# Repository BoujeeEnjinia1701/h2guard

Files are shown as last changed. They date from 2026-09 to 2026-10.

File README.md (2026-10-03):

# H2Guard

     

**Area:** Hydrogen · **TRL:** 3 of 9 (proof of concept on paper) · **Value-engineering target:** USD 265 (estimated cost USD 411) · **Difficulty:** 3 of 5

A hydrogen leak detector and ventilation interlock for small labs, workshops and electrolyzer rooms: it senses hydrogen near the ceiling, runs a fan and cuts the supply when readings rise.

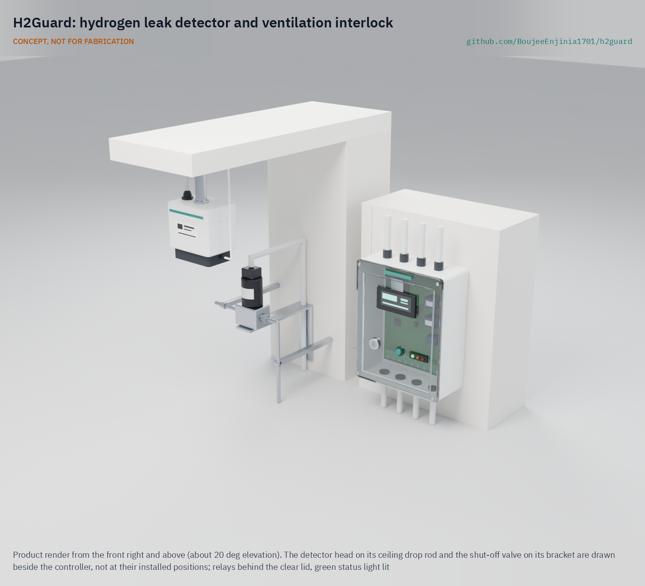
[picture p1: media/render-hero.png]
H2Guard: hydrogen leak detector and ventilation interlock, product render


[Exploded render](media/render-exploded.png) · [Detail render](media/render-detail.png) · [Interactive 3D model](media/viewer.html) · [Concept blueprint (PDF)](media/concept-blueprint.pdf) · [General arrangement HGD-DWG-001 (PDF)](cad/drawings/HGD-DWG-001.pdf) · [Sizing calculations](docs/04-calcs/01-sizing.md) · [Prototype build plan](docs/05-build-plan.md) · [Design decisions register](docs/06-design-decisions.md) · [Review note](docs/REVIEW.md)

## Concept rationale

Detection, ventilation and automatic shutoff form the basic safety chain for any room where hydrogen is used, and each link has to work when the others fail. H2Guard puts that chain in one small kit: a ceiling detector head with a catalytic sensor for the trip and a metal oxide sensor for early warning, a continuously running exhaust fan, and a normally closed valve that holds the supply open only while the controller, the sensors and the fan are all healthy. A hardware comparator can close the valve without the firmware, so a software bug cannot keep gas flowing.

It is open and garage-buildable because the people now starting to use hydrogen, teachers, technicians and small startups, need to see how a safety system decides, not just trust a sealed box. Every set point and failure response is written down, the self-built parts run on 24 V DC from a certified supply, and the parts are off the shelf. It is a teaching and research prototype, not a certified gas detection system, and the documents say where it falls short of one.

## Burning platform

Hydrogen is moving into classrooms, startups and small labs faster than safe practice is reaching them. Installed water electrolysis capacity reached about 2 GW in 2024, with more than 1 GW added in the first seven months of 2025 ([IEA, Global Hydrogen Review 2025](https://www.iea.org/reports/global-hydrogen-review-2025/executive-summary)). The gas is flammable in air from about 4 % to 74 % by volume, ignites with about 0.02 mJ, and collects under ceilings in poorly ventilated rooms ([US DOE](https://www1.eere.energy.gov/hydrogenandfuelcells/pdfs/h2_safety_fsheet.pdf)).

Small-scale accidents show the cost of missing safeguards. In 2016 a hydrogen and oxygen mixture exploded in a University of Hawaii lab, costing a researcher an arm; the state safety regulator cited the university for 15 violations with $115,500 in fines ([C&EN, 2016](https://cen.acs.org/articles/94/web/2016/09/University-Hawaii-fined-115500-lab.html)), later settled at nine violations and $69,300 ([Honolulu Star-Advertiser, 2016](https://www.staradvertiser.com/2016/10/07/breaking-news/state-agrees-to-reduced-violations-fines-in-uh-lab-explosion/)). In 2019 a hydrogen tank used by a fuel cell company at a technopark in Gangneung, South Korea, exploded, killing two people and injuring six ([Korea Herald](https://www.koreaherald.com/article/2006624)). An analysis of the European HIAD 2.0 incident database found organizational factors in about half of the relevant events ([Wen et al., 2022](https://www.sciencedirect.com/science/article/pii/S0360319922012976)), which is the case for safeguards that act automatically.

## Where it could be used

### By industry

| Industry | Use |
| --- | --- |
| Education | Protection and teaching aid for school and university hydrogen demonstrations, including the lab's H2Bench |
| Hydrogen and fuel cell startups | Interim protection for a small test room before a certified system is installed |
| Analytical laboratories | Room-level leak detection near hydrogen generators used as gas chromatography carrier gas |
| Materials handling and backup power | Monitoring battery charging rooms, where US rules require ventilation for gases from charging batteries ([OSHA 1910.178(g)(2)](https://www.osha.gov/laws-regs/regulations/standardnumber/1910/1910.178)), and small fuel cell backup rooms |
| Vocational training | Hands-on teaching of set points, interlocks and bump testing for hydrogen technicians |
| Makerspaces | A clear rule set and hardware for members experimenting with electrolysis |

### By country or region

| Country or region | Why it matters there |
| --- | --- |
| United States | After the 2016 University of Hawaii lab explosion, the state safety regulator cited the university for 15 violations with $115,500 in fines ([C&EN, 2016](https://cen.acs.org/articles/94/web/2016/09/University-Hawaii-fined-115500-lab.html)), settled later that year at nine violations and $69,300 ([Honolulu Star-Advertiser, 2016](https://www.staradvertiser.com/2016/10/07/breaking-news/state-agrees-to-reduced-violations-fines-in-uh-lab-explosion/)) |
| South Korea | A hydrogen tank explosion at a Gangneung technopark in 2019 killed two visitors from venture businesses and research groups ([Korea Herald](https://www.koreaherald.com/article/2006624)) |
| European Union | The EU hydrogen strategy aims for at least 40 GW of renewable hydrogen electrolyzers by 2030 ([European Commission, COM(2020) 301](https://eur-lex.europa.eu/legal-content/EN/TXT/?uri=CELEX:52020DC0301)), which needs many trained technicians |
| China | Holds 65 % of the world's installed and committed electrolyzer capacity ([IEA](https://www.iea.org/reports/global-hydrogen-review-2025/executive-summary)), with a large and growing training need |
| India | The National Green Hydrogen Mission targets at least 5 Mt per year of green hydrogen by 2030 and includes a skills program ([PIB, 2023](https://www.pib.gov.in/PressReleasePage.aspx?PRID=1888547)); colleges and startups need low-cost lab safety |
| Namibia | The government runs a national green hydrogen program ([Namibia Green Hydrogen Programme](https://gh2namibia.com/)); the vice-chancellor of the Namibia University of Science and Technology has warned of a talent gap of up to 130,000 workers by 2040 ([The Namibian, 2025](https://www.namibian.com.na/namibia-risks-130-000-worker-shortage-in-green-hydrogen-sector/)), and the university's IGNITE GH2 project is retraining 685 unemployed graduates and 40 instructors ([NUST, 2026](https://www.nust.na/igniting-namibias-green-hydrogen-dream-science-building-national-tvet-workforce-green-hydrogen)) |

## What sparked the idea

The idea traces back to the New London School explosion in Texas on March 18, 1937. Gas from a faulty connection on a cheap residue gas line collected unnoticed in a nearly closed space beneath the school and exploded, killing about 298 students and teachers; the most important result was a state law requiring a distinctive malodorant in commercial and industrial gas so that people could smell a leak ([Texas State Historical Association, Handbook of Texas](https://www.tshaonline.org/handbook/entries/new-london-school-explosion)). That fix does not carry over to hydrogen. It is colorless and odorless, and there are no known odorants light enough to travel with it, so by the time an odorant could be smelled the gas may already be above its flammability limit ([OSHA](https://www.osha.gov/green-jobs/hydrogen/fire-explosion)). A room that uses hydrogen therefore needs what the nose cannot give it: an electronic detector at the ceiling, where the gas collects, tied to ventilation and a valve that shuts the supply without waiting for a person to notice. H2Guard is that chain, sized for the classrooms and small labs now taking up hydrogen.

## Problem

Small hydrogen setups in schools and startups often have no gas detection or interlock because commercial systems are priced for industrial plants.

Full problem statement: [docs/01-problem.md](docs/01-problem.md)

## Concept

A detector head at the ceiling above the hydrogen source measures 0 to 100 % of the lower flammability limit (LFL). A wall controller keeps an exhaust fan running and holds a normally closed valve on the supply open. At 10 % LFL it warns and boosts the fan; at 25 % LFL it closes the valve, sounds the alarm and latches until a key reset. Power loss, sensor faults, a stopped fan, lost airflow (a pressure switch on the fan inlet) or a crashed controller also close the valve, and a hardware comparator trip works without the firmware. The TRL 3 calculations give 35.7 s from a 5 L/min leak to the valve closing (with an assumed 30 s sensor response), and about 5 % LFL in the 30 m3 reference room with the fan running. They also show that the design leak trips the system at once only if the detector head is on the plume axis above the leak. Two rules accepted by Amish cover the rest: a warning held for 5 min also closes the valve (about 5.6 min for the design leak off the axis), and the head hangs from the ceiling on a short drop rod directly above the likely leak point.

Full design precis: [docs/02-concept.md](docs/02-concept.md) · Requirements: [docs/03-requirements.md](docs/03-requirements.md) · Calculations: [docs/04-calcs/01-sizing.md](docs/04-calcs/01-sizing.md) · Decisions: [DDR-001](docs/decisions/0001-trl2-review-decisions.md), [DDR-002](docs/decisions/0002-recommendations-accepted.md), [DDR-003](docs/decisions/0003-design-for-construction.md), [register](docs/06-design-decisions.md)

## Key components

- Detector head on a ceiling drop rod, with a catalytic hydrogen sensor (0 to 100 % LFL) and a metal oxide early-warning sensor, behind thin sintered flame arrestors, with a drip skirt that doubles as a bump test cup
- Controller in a clear-lid box with an independent hardware trip (latched comparator and series relay), display, key-switch reset, event log, a dry-contact output for the host bench and a bump test gas port
- Certified 24 V DC power supply
- 150 mm mixed-flow exhaust fan at high level, running continuously, with a differential pressure switch that proves airflow, and a low-level make-up air grille
- Normally closed 24 V DC solenoid valve rated for hydrogen on the supply
- Oxygen sensor option where inert gas cylinders share the room
- Sounder and beacon

The priced bill of materials is in [bom/bom.csv](bom/bom.csv). Value-engineering target: USD 265. Estimated cost of the constructable design: USD 411 (USD 146 over the target), at indicative prices; the [design decisions register](docs/06-design-decisions.md) lists the main cost drivers and savings worth trying. The parametric model is `cad/src/model.py`, with STEP and STL exports in `cad/step/` and `cad/stl/`.

## Building the prototype

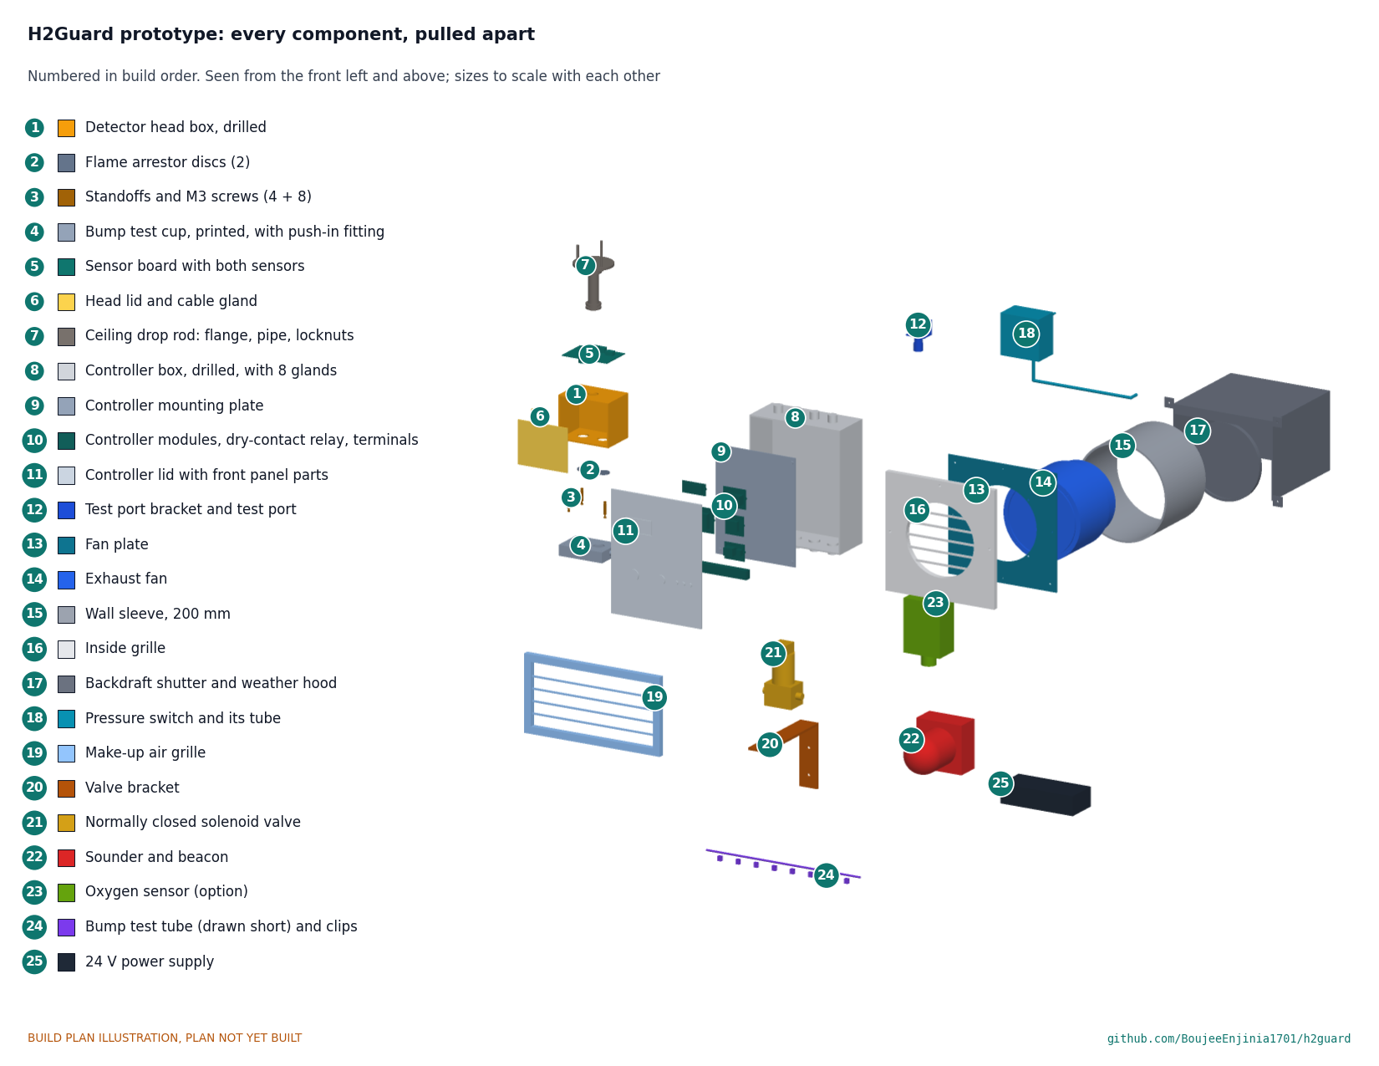
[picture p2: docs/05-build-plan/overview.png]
Every H2Guard component, pulled apart and numbered in build order


The [prototype build plan](docs/05-build-plan.md) (HGD-BLD-001) shows how to make and fit every component, with a making sketch for each made part, close-ups of the joints and a picture for each of the 15 assembly steps. Nine parts are made or drilled in a small workshop (the two boxes and the controller lid, the printed bump test cup, the sensor board and four aluminium brackets and plates); the rest are bought. Making the design buildable added standoffs, a mounting plate, a fan plate with a 200 mm wall sleeve and brackets for the test port and valve ([HGD-DDR-003](docs/decisions/0003-design-for-construction.md)). It is a plan: nothing has been built or tested.

## Safety

> Hydrogen is flammable in air from about 4 % to 74 % by volume. This is a research and teaching prototype and not a certified gas detection system; use certified equipment for any real installation. Its parts are not rated for hazardous areas. It protects only against small, flow-limited leaks, and only with its head hung directly over the leak point; keep hydrogen inventories small, and have gas fittings made and leak-tested by a competent person. Mains power enters only through a certified supply.

## Repository layout

| Folder | Contents |
| --- | --- |
| `docs/` | Problem, concept, requirements, calculations and design decisions |
| `cad/src/` | build123d Python source, the source of truth for all geometry |
| `cad/step/`, `cad/stl/` | Exported models for FreeCAD, other CAD tools and printing |
| `cad/drawings/` | 2D sketches and dimensioned drawings |
| `bom/` | Bill of materials |
| `electronics/` | KiCad schematics and PCB layouts |
| `firmware/` | Microcontroller code |
| `media/` | Renders, perspectives and photos |
| `build-log/` | Dated prototyping notes |

## Documentation

Controlled documents follow the portfolio [documentation standard](.kit/STANDARDS.md). Each carries a document ID (HGD-PRC-001 for the precis), a version and a revision history. Branded PDFs are built with `python .kit/render.py` and attached to GitHub Releases when a document is tagged, for example `HGD-PRC-001/v1.0`.

## Credits

Designed by Amish Chadha. See [CONTRIBUTORS.md](CONTRIBUTORS.md) for roles. To cite this design, use [CITATION.cff](CITATION.cff) (GitHub shows it as "Cite this repository").

AI assistance (Claude) was used to accelerate concept renders, prototype documentation and first-pass sizing calculations. Design direction and all decisions are Amish Chadha's, recorded in this repository's decision records (`docs/decisions/`).

## Licenses

- **Hardware** (CAD, drawings, BOM, electronics): [CERN-OHL-S v2](LICENSE)
- **Software** (firmware, scripts, notebooks): [MIT](LICENSE-SOFTWARE)

A project of the [Design Molecule](https://designmolecule.com) lab.

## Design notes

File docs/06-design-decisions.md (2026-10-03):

---
doc_id: HGD-DEC-001
title: H2Guard design decisions register
project: H2Guard
doc_type: Design decisions register
version: "0.4"
status: Draft
date: '2026-10-03'
author: Amish Chadha
license: CERN-OHL-S-2.0
revisions:
- version: "0.1"
  date: '2026-10-01'
  author: Amish Chadha
  change: Register opened with the build plan; open decisions gathered from the review note and the decision records; budget treated as a value-engineering target
- version: "0.2"
  date: '2026-10-02'
  author: Amish Chadha
  change: Amish approved the recommendations for open decisions 1 to 12 (HGD-DDR-003 accepted; head on a ceiling drop rod); moved to decisions made
- version: "0.3"
  date: '2026-10-02'
  author: Amish Chadha
  change: Decisions carried into the model, BOM and calculations; value engineering re-priced (USD 411); items to confirm for the drop rod, pressure switch and dry-contact relay
- version: "0.4"
  date: '2026-10-03'
  author: Amish Chadha
  change: "Amish accepted the cost overrun against the value-engineering target on 2026-10-03; row added to decisions made; value engineering section updated"
---

# H2Guard design decisions register

Every design decision still to be made, and every decision made, in one place. Each decision is argued in full in its decision record under `docs/decisions/` or in the review note; this register is the index Amish works from. The build plan (`docs/05-build-plan.md`) describes the design as it stands and does not list open decisions.

## Open decisions

None. All open decisions were decided on 2026-10-02.

## To confirm when parts are bought

| # | What to confirm | Why it matters | Source |
| --- | --- | --- | --- |
| 1 | The catalytic sensor's response time (t90), power and hydrogen output, from its datasheet | R4 assumes a t90 of 30 s; R1's 1 % LFL resolution needs the output | HGD-CAL-001, F3 |
| 2 | The sensor can is about 20 mm across and 17 mm tall | The standoff length sets its 2.2 mm gap above the disc | HGD-DDR-003, P4 |
| 3 | The head box has its lid on a 110 x 90 face | The ports, gland and drop rod hole assume it | HGD-DDR-003, P3 |
| 4 | The controller box's boss spacing and corner fixing holes | They set the mounting plate holes and the wall screws | HGD-DDR-003, P6, P8 |
| 5 | The fan's body fits a 200 mm sleeve (about 180 mm across or less) and has fixing holes in its inlet face | The fan plate holds it by those holes | HGD-DDR-003, P10 |
| 6 | The fan's curve gives at least 300 m³/h against about 60 Pa | R7 rests on an assumed curve | HGD-CAL-001, G3 |
| 7 | The valve has two tapped holes underneath, 36 mm apart, and is rated for hydrogen with a stated seat leak rate | The bracket holes; the leaking-seat fault in Table 4 of HGD-CAL-001 | HGD-DDR-003, P11; HGD-DDR-001, O5 |
| 8 | The pressure switch can be set to about 3 Pa (a low-range air switch) | The fan inlet tap gives only 5.7 Pa at the continuous flow; a common 20 Pa minimum switch would prove flow only on boost | HGD-CAL-001, G6; decision 6 |
| 9 | The floor flange, pipe nipple and conduit locknuts share one 1/2 in thread, and the ceiling takes the flange screws | The drop rod holds the head over the apparatus | HGD-CAL-001, E7; decision 2 |
| 10 | The dry-contact relay's contact rating suits H2Bench's supply cut-off circuit | H2Bench switches its own supply through it | Decision 9 |

## Value engineering

Value-engineering target: USD 265. Estimated cost of the constructable design: USD 411 (USD 146 over the target). The estimate comes from the 21-line bill of materials at indicative prices; the target is `budget_usd`, a hypothetical control target, not a limit. Two options are priced with quantity 0 and are not in the total: the oxygen sensor (USD 110) and the fan with its motor outside the air stream (USD 450, in place of the USD 55 fan). Main cost drivers and savings worth trying:

Amish accepted this overrun on 2026-10-03: the estimated cost of USD 411 against the USD 265 target (USD 146 over). Amish: "Cost over target - i accept all the cost variations and overruns". It stays reported against the target as an accepted overrun, and the savings below remain worth trying.

- The largest lines are the hydrogen-rated valve (USD 95), the exhaust fan with its grille, sleeve, shutter and hood (USD 55), the catalytic sensor (USD 35), the pressure switch and tubing (USD 30) and the controller modules (USD 25). Together they are about 60 % of the cost.
- Making the design constructable added USD 25: the made brackets and plates (USD 14), the 200 mm wall sleeve (USD 5), standoffs, screws and epoxy (USD 4) and the cup's push-in fitting and tube clips (USD 2).
- The decisions of 2026-10-02 added USD 122: the hydrogen-rated valve (USD 65 more than the brass valve), the pressure switch and tubing (USD 30), the ceiling drop rod (USD 11), the dry-contact relay and terminal (USD 6), the clear-lid controller box (USD 5) and more cable (USD 5).
- Savings worth trying: a printed controller mounting plate in place of aluminium sheet (about USD 3); buying the fan as a kit with its own shutter and hood; one combined controller board at TRL 4 in place of separate bought modules; and, where the room already has mechanical extract at high level, using it in place of the kit fan and grille (USD 63), which would bring the kit to about USD 348; and the brass valve at USD 30, if its maker states hydrogen compatibility and a seat leak rating and it passes the seat leak proof test (USD 65 less).

## Decisions made

| Date | Decision | Decided by | Record |
| --- | --- | --- | --- |
| 2026-09-25 | D1 to D9: catalytic plus metal oxide sensors (certified sensor as the upgrade); set points 10 % and 25 % LFL; normally closed valve; continuous ventilation with boost; inventory rule (R9); key-switch reset and one head per room; a university teaching lab first; independent hardware trip; 24 V DC with a certified supply | Amish: "i accept all your recommendations, go with them across all repos." | HGD-DDR-001, HGD-DDR-002 |
| 2026-09-25 | Budget figure USD 265, now treated as the value-engineering target | Amish, same instruction; on 2026-10-01: "the budgets are a hypothethical control target to ensure we are thinking along a value engineering lens" | HGD-DDR-002 |
| 2026-09-25 | Timed escalation: a warning held 5 min closes the valve and latches | Amish, same instruction | HGD-DDR-002 |
| 2026-09-25 | Head placement rule: a head directly above each likely leak point; offset limit set by test at TRL 4 | Amish, same instruction | HGD-DDR-002 |
| 2026-09-25 | R13 scope: the fan and grille wall openings are builder's work | Amish, same instruction | HGD-DDR-002 |
| 2026-09-25 | H2Bench to reflect the inventory rule | Amish, same instruction | HGD-DDR-002 |
| 2026-09-30 | Make the design physically buildable while drawing the build plan; keep open decisions out of the build plan | Amish: "If you are realising that the design cannot be built as per concept - fix the design assumptions to match and be physically feasible as you draw the illustrations." | HGD-DDR-003 (changes accepted on 2026-10-02, below) |
| 2026-10-02 | Design for construction accepted: the changes P1 to P11, as made; the head position is settled separately (decision 2) | Amish: "i approve your recommendations for all 555 open decisions." | HGD-DDR-003, Table 1 |
| 2026-10-02 | The head hangs from the ceiling on a drop rod directly over the apparatus; wall mounting is allowed only if the TRL 4 plume test shows a trip at the wall position (the wall position puts the ports 260 mm from the apparatus centre against a plume radius of about 141 mm) | Amish: "i approve your recommendations for all 555 open decisions." | HGD-DDR-003, A1 |
| 2026-10-02 | Fan motor in the sleeve accepted for the supervised teaching prototype; any room used without close supervision gets a fan with its motor outside the air stream | Amish: "i approve your recommendations for all 555 open decisions." | HGD-DDR-003, A2 |
| 2026-10-02 | An oxygen sensor is added, as a standard kit option, whenever inert gas cylinders share the room | Amish: "i approve your recommendations for all 555 open decisions." | HGD-DDR-001, O2 |
| 2026-10-02 | Set points and the inventory rule come from the stricter of the national code and ISO 26142, and from the host institution's safety office where its rules are stricter; 10 % and 25 % LFL stay the defaults | Amish: "i approve your recommendations for all 555 open decisions." | HGD-DDR-001, O3 |
| 2026-10-02 | A differential pressure switch at the fan proves airflow | Amish: "i approve your recommendations for all 555 open decisions." | HGD-DDR-001, O4 |
| 2026-10-02 | The valve is rated for hydrogen with a stated seat leak rate; the low-cost brass valve is accepted only if its maker states hydrogen compatibility and a seat leak rating and it passes a seat leak proof test at TRL 4 | Amish: "i approve your recommendations for all 555 open decisions." | HGD-DDR-001, O5 |
| 2026-10-02 | The 1 % full-span bump test trips the system, as planned; the pass level is set once the cup delivery factor is measured | Amish: "i approve your recommendations for all 555 open decisions." | Review note, 2026-09-25 |
| 2026-10-02 | A dry-contact relay output that opens on a trip or loss of power is added, for H2Bench to cut its own supply | Amish: "i approve your recommendations for all 555 open decisions." | Review note, 2026-09-25 |
| 2026-10-02 | The render layout is kept, with a caption saying the head and valve are drawn beside the controller | Amish: "i approve your recommendations for all 555 open decisions." | Review note, 2026-09-26, item 1 |
| 2026-10-02 | A clear-lid IP65 controller box, added to the BOM at its next revision | Amish: "i approve your recommendations for all 555 open decisions." | Review note, 2026-09-26, item 2 |
| 2026-10-02 | Leaving the fan, grille, sounder, beacon and supply out of the product renders accepted | Amish: "i approve your recommendations for all 555 open decisions." | Review note, 2026-09-26, item 3 |
| 2026-10-03 | Cost overrun accepted: the estimated cost of USD 411 against the USD 265 target (USD 146 over) | Amish: "Cost over target - i accept all the cost variations and overruns" | [REVIEW.md](REVIEW.md), session 2026-10-03 |

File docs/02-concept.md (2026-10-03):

---
doc_id: HGD-PRC-001
title: H2Guard design precis
project: H2Guard
doc_type: Design precis
version: "0.7"
status: Draft
date: '2026-10-02'
author: Amish Chadha
license: CERN-OHL-S-2.0
revisions:
- version: "0.1"
  date: '2026-09-25'
  author: Amish Chadha
  change: Initial scaffold
- version: "0.2"
  date: '2026-09-25'
  author: Amish Chadha
  change: Populate to TRL 2 (architecture, components, first-order numbers, design choices, safety, media)
- version: "0.3"
  date: '2026-09-25'
  author: Amish Chadha
  change: TRL 3 update; design choices adopted for TRL 3 per HGD-DDR-001 (pending Amish's review); numbers from HGD-CAL-001; fan re-specified, thinner arrestors, bump test cup and port added; series trip relay; parametric model and drawing HGD-DWG-001
- version: "0.4"
  date: '2026-09-25'
  author: Amish Chadha
  change: Recommendations accepted by Amish (DDR-002); timed escalation firmware rule, head placement rule, budget $265, R13 scope; drawing HGD-DWG-001 to Rev P2
- version: "0.5"
  date: '2026-10-01'
  author: Amish Chadha
  change: Design made constructable (HGD-DDR-003) with a build plan (HGD-BLD-001); cost against the value-engineering target; drawing HGD-DWG-001 to Rev P4
- version: "0.6"
  date: '2026-10-02'
  author: Amish Chadha
  change: "Decisions of 2026-10-02 carried in: ceiling drop rod, pressure switch, hydrogen-rated valve, oxygen sensor option, set point sources, bump test, relay output, clear lid, fan motor rule"
- version: "0.7"
  date: '2026-10-02'
  author: Amish Chadha
  change: Model, BOM and calculations updated to the decisions of 2026-10-02 (HGD-CAL-001 v0.4); components table, key numbers and safety notes brought into line; drawing HGD-DWG-001 to Rev P5
---

# H2Guard design precis

H2Guard protects one small room where hydrogen is used. A detector head at the ceiling carries a catalytic sensor that reads 0 to 100 % of the lower flammability limit (LFL) and a metal oxide sensor for early warning. A wall controller at chest height keeps a 150 mm exhaust fan running at high level, holds a normally closed solenoid valve on the hydrogen supply open only while all is well, and drives a sounder and beacon. At 10 % LFL it warns and boosts the fan; at 25 % LFL it closes the valve and latches the alarm. Loss of power, a sensor fault, a stopped fan, lost airflow or a crashed controller all close the valve, and a hardware comparator opens a relay in series with the valve without the firmware. The TRL 3 calculations (HGD-CAL-001) give 35.7 s from a leak to the valve closing with an assumed 30 s sensor t90, about 5 % LFL in the 30 m3 room for the 5 L/min design leak with the fan running, and an estimated cost of USD 411 for the constructable design against a USD 265 value-engineering target (USD 146 over). A warning held for 5 min also closes the supply, so a leak that the head sees off the plume axis is stopped within about 6 min. H2Guard is a research and teaching prototype, not a certified gas detection system.

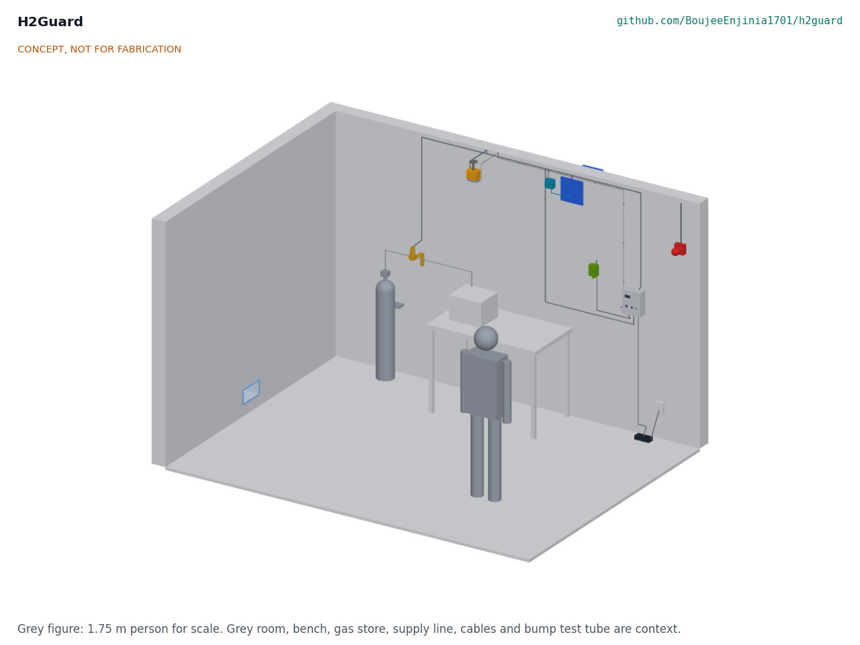
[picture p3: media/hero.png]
Hero render


*Figure 1. H2Guard in the 30 m3 reference room, with a 1.75 m person for scale. Detector head (orange) on its ceiling drop rod over the bench apparatus, exhaust fan (blue) high on the back wall, make-up air grille low on the far side wall, solenoid valve (gold) on the supply line, controller with its bump test port, and beacon near the door. Grey parts are context. Built from the parametric model.*

## How it works

1. **Sense.** Hydrogen rises from a leak as a buoyant plume and spreads under the ceiling. The detector head hangs from the ceiling on a short drop rod directly above the likely leak point, with its sensor ports 175 mm below the ceiling. The placement rule (HGD-DDR-002) puts a head over each likely leak point, with a second head where leak points are far apart; the plume is only about 141 mm in radius at the ports, and the allowed horizontal offset is to be set from a measured plume width at TRL 4. The catalytic sensor measures 0 to 100 % LFL and sets the warning and trip. The metal oxide sensor responds from about 30 ppm and shows small, slow leaks as a trend long before the catalytic reading moves; it never trips the system alone, because humidity and other vapors affect it. Each sensor sits about 2 mm behind a 2 mm sintered arrestor disc, which adds about 1.5 s of lag.
2. **Decide.** The controller reads both sensors. The microcontroller handles set points, display, logging and self-test, and switches the valve through a MOSFET. In parallel, a hardware window comparator watches the catalytic sensor bridge: above the trip level, or if the bridge reads open or shorted, it sets a hardware latch that opens a relay in series with that MOSFET. Either switch opening closes the valve, and only the key resets the latch.
3. **Act.**
   - **Normal:** fan at continuous speed, valve energized (open), green light.
   - **Warning, 10 % LFL (0.4 % vol):** fan to boost, amber light, intermittent sounder. Clears itself when the reading falls. If the warning is held for 5 min, the microcontroller closes the valve and latches as for a trip (timed escalation, HGD-DDR-002). This is a firmware rule; the hardware comparator still acts only at 25 % LFL.
   - **Trip, 25 % LFL (1.0 % vol):** valve de-energized (closed), fan on boost, continuous sounder and red beacon. Latched: the supply stays closed until someone turns the reset key and the reading is below 10 % LFL.
   - **Fault:** any loss of 24 V power, sensor fault, heater failure, watchdog timeout (1 s), fan stop (no tachometer pulses for 10 s) or lost airflow (the pressure switch on the fan inlet not proving flow for 10 s with the fan running) closes the valve and shows the fault. A dry-contact relay, held while all is well, opens on a trip, a fault or loss of power so that H2Bench can cut its own supply.
4. **Ventilate.** The fan runs all the time, so it is never switched on in a flammable mixture, and so no gas can flow unless the room is being ventilated. Make-up air enters through a low grille on the far side of the room, sweeping the room toward the high exhaust.
5. **Record and test.** The controller logs readings, warnings, trips, faults and resets. A test button runs the sounder, beacon, fan boost and valve close. For a bump test, certified 1 % vol hydrogen span gas is connected to a capped port beside the controller; a 4 mm tube carries it up the cable route to a nozzle in the drip skirt under the head, which acts as a test cup. The reading settles in about 67 s. Because 1 % vol is the trip level, a full-span bump test also trips the system and proves the chain.

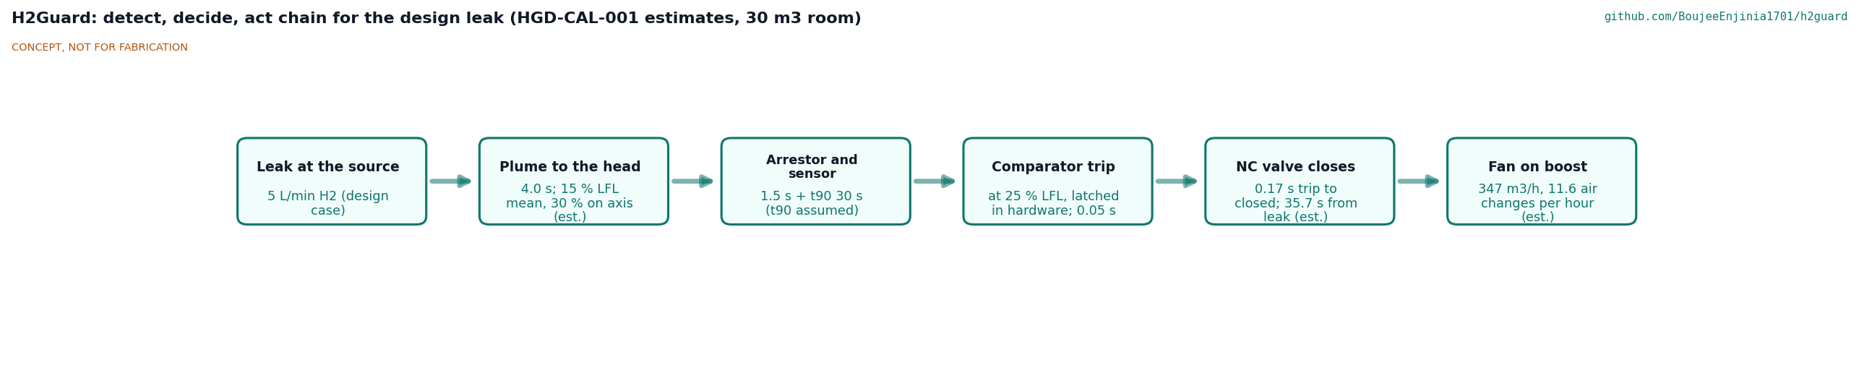
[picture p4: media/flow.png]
Detect, decide, act chain


*Figure 2. Detect, decide and act chain for the design leak in the 30 m3 reference room, with values from HGD-CAL-001. They are estimates; the sensor t90 is an assumption not yet confirmed from a datasheet.*

## Main components

Table 1. Main components. Numbers match `bom/bom.csv`, Figure 3 and drawing HGD-DWG-001.

| # | Component | Choice | Notes |
| --- | --- | --- | --- |
| 1 | Detector head enclosure | ABS or polycarbonate box 110 x 80 x 90 mm, two 22 mm sensor ports facing down | On the ceiling drop rod (17) directly above the source, ports 175 mm below the ceiling |
| 2 | Catalytic hydrogen sensor | Catalytic (pellistor) sensor with hydrogen response, 0 to 100 % LFL, for example Figaro TGS6812 | Primary trip sensor; needs oxygen and can be poisoned by silicones |
| 3 | Metal oxide hydrogen sensor | About 30 to 3,000 ppm, for example Figaro TGS2616-C00 | Early warning and trend only |
| 4 | Flame arrestor discs and bump test cup | Sintered stainless discs 25 x 2 mm, pores 50 µm or less; drip skirt 96 x 66 x 22 mm forming the test cup | Not a certified flameproof assembly |
| 5 | Controller enclosure | IP65 polycarbonate wall box 200 x 250 x 90 mm with a clear lid, eight cable glands | Top 1,025 mm below the ceiling |
| 6 | Controller board | RP2040-class microcontroller with 4 MB flash; comparator with hardware latch and series relay; drivers for valve, fan and alarm; tachometer and pressure switch inputs; event log | Firmware beyond a labeled sketch is TRL 4 work |
| 7 | Front panel | OLED display, key-switch reset, test button, status lights | The key keeps students from clearing a trip |
| 8 | 24 V DC power supply | Certified plug-in supply, 24 V, 60 W | Only mains part; bought certified |
| 9 | Exhaust fan | 150 mm mixed-flow EC duct fan, 24 V, about 450 m3/h free air, 200 Pa shut-off, tachometer; grille, sleeve, backdraft shutter, weather hood | Re-specified at TRL 3; runs continuously at about 43 % speed |
| 10 | Make-up air grille | Low-level wall grille 300 x 160 mm with insect mesh | Far side of the room from the fan |
| 11 | Normally closed solenoid valve | 1/4 in, direct acting, stainless steel, rated for hydrogen with a stated seat leak rate, 24 V DC, 0 to 10 bar, Zener clamp | After the regulator; closes on loss of power |
| 12 | Sounder and beacon | 24 V, about 90 dB at 1 m, red flashing | By the door, top 450 mm below the ceiling |
| 15 | Bump test port and tube | Capped push-fit port beside the controller, about 3.1 m of 4 mm tube across the ceiling to the cup nozzle | New at TRL 3 for R12 |
| 17 | Ceiling drop rod | 1/2 in floor flange on the ceiling, 89 mm pipe nipple, locknuts either side of the head top | Holds the head with its ports over the apparatus |
| 18 | Differential pressure switch | Low-range air pressure switch beside the fan, tubed to a static tap in the fan inlet | Proves airflow; no flow closes the valve |
| 19 | Dry-contact output | Relay and 2-way terminal on the controller mounting plate | Opens on a trip, a fault or loss of power |
| 20 | Oxygen sensor (option) | Electrochemical transmitter, 4 to 20 mA, cell at breathing height | Fitted whenever inert gas cylinders share the room |
| 21 | Fan with motor outside the air stream (option) | Bifurcated 150 mm duct fan in place of line 9 | For rooms used without close supervision |

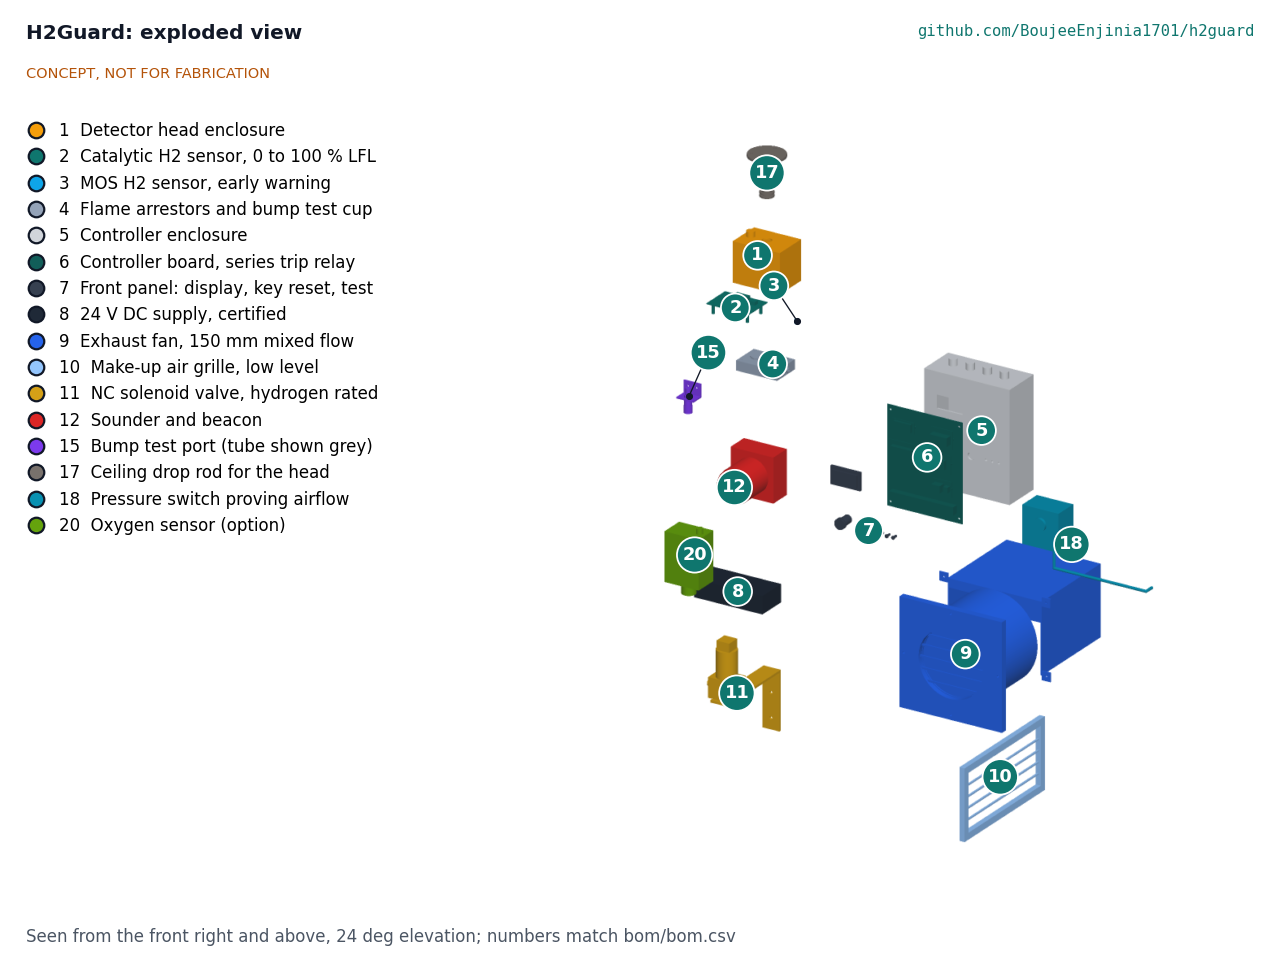
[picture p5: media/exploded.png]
Exploded view


*Figure 3. Exploded view of the H2Guard parts with BOM numbers. Cabling (BOM line 13), fixings (line 14), the dry-contact relay (line 19, on the controller board) and the alternative fan (line 21) are not shown separately.*

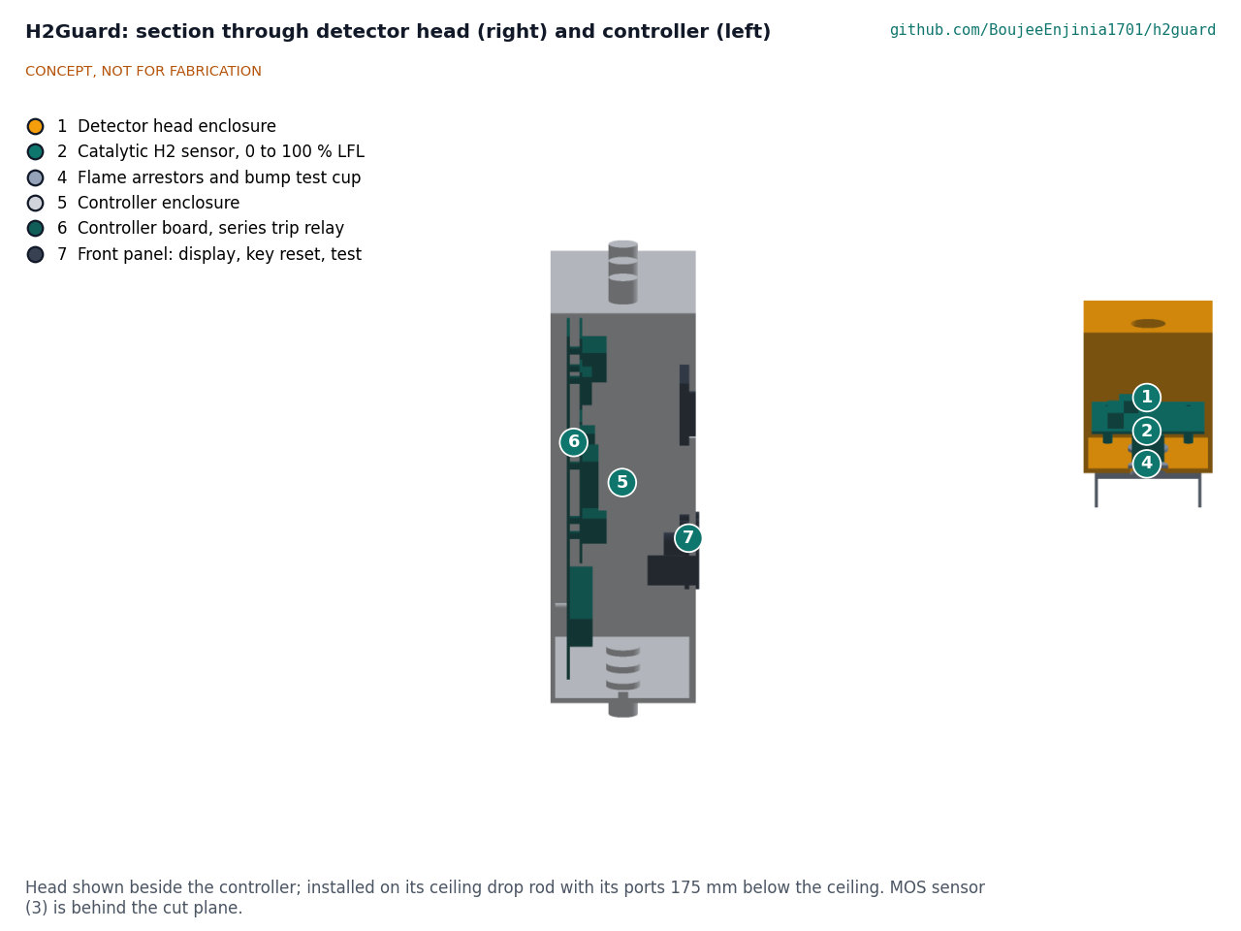
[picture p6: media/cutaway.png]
Cutaway


*Figure 4. Sections through the controller (left) and the detector head (right), each cut on a vertical plane and seen from the side. The head section passes through the catalytic sensor, its arrestor disc and the bump test cup. The head is drawn beside the controller for this view.*

The general arrangement drawing [HGD-DWG-001](../cad/drawings/HGD-DWG-001.pdf) (Rev P5) gives the mounting heights and main dimensions from the parametric model `cad/src/model.py`. The blueprint concept sheet ([PDF](../media/concept-blueprint.pdf)) and the [interactive 3D model](../media/viewer.html) show the parts in place. The design is constructable: every part can be made or bought and has a fixing (HGD-DDR-003), and the [prototype build plan](05-build-plan.md) (HGD-BLD-001) shows how each is made and fitted. The changes for construction are the openings in the bump test cup, 22 mm ports with the arrestor discs bonded on a ledge, standoffs that hold the sensor board and cup, a mounting plate and drilled lid in the controller, a bracket for the test port, a 200 mm wall sleeve and fan plate for the fan, and a bracket for the valve. The decisions of 2026-10-02 added the ceiling drop rod, the pressure switch, the dry-contact output and the oxygen sensor option to the model.

## Key numbers

All values are from HGD-CAL-001, which gives the method and assumptions. They are first-principles estimates.

Table 2. Key numbers for the 30 m3 reference room and the 5 L/min design leak.

| Quantity | Value |
| --- | --- |
| Hydrogen from a 100 W electrolyzer | 0.39 L/min |
| Ceiling layer (0.3 m) to 25 % LFL without ventilation | 7.2 min (whole room mixed: 60 min) |
| Room and upper layer with 150 m3/h exhaust | 5.0 % LFL (2.5 % LFL on boost) |
| Plume at the detector head | About 15 % LFL mean, about 30 % LFL on the plume axis |
| Leak to valve closed | 35.7 s with an assumed 30 s sensor t90; 0.17 s from trip to closed |
| Hydrogen released before closing | 3.0 L, plus 0.47 L in the line downstream |
| Fan delivery against duct losses | 347 m3/h at full speed (the TRL 2 fan gave 237 m3/h) |
| Inventory limit | 300 L at 1 atm (25.1 g); a 0.13 mm orifice at 10 bar gauge limits a failure to 5 L/min |
| Power | 13.5 W normal, 48.7 W warning, 40.3 W trip (49.2 W peak with the oxygen sensor) |
| Airflow proving | Fan inlet tap 5.7 Pa at 150 m3/h, 30.5 Pa at full speed; switch set at about 2.8 Pa; no flow gives about 0 Pa |
| Bump test | About 67 s; 1.36 L of span gas per test |
| Timed escalation, off-axis design leak | Valve closed at 5.6 min, 28 L released, room about 1.9 % LFL |
| Estimated cost | Value-engineering target: USD 265. Estimated cost of the constructable design: USD 411 (USD 146 over the target); oxygen sensor option USD 110 more |

Two findings matter for the design. First, the design leak trips the system only if the head is on the plume axis; beside it, the head sees about 15 % LFL and warns without closing the supply, although the room stays at about 5 % LFL. Second, a fan rated at the boost flow in free air cannot deliver it through a real duct, so the fan is re-specified. Amish accepted two remedies for the first on 2026-09-25 (HGD-DDR-002): the timed escalation and the head placement rule. On 2026-10-02 he decided that the head hangs on a ceiling drop rod directly over the apparatus; the model now puts the ports 0 mm from the apparatus centre, inside the plume.

## Key design choices

The choices below are decided by Amish, 2026-09-25: go with recommendation (HGD-DDR-001, confirmed by HGD-DDR-002).

1. **Catalytic sensor for the trip, metal oxide sensor for early warning** (D1). Options were (a) catalytic plus metal oxide (about $50 of sensors); (b) a certified molecular property spectrometer sensor (about $249, t90 under 20 s, poisoning resistant, [NevadaNano](https://nevadanano.com/mps-hydrogen-gas-sensor/)); (c) metal oxide only. Adopted: (a) for the teaching prototype, with (b) documented as the upgrade for any room used without close supervision.
2. **Normally closed valve, energize to open** (D3). Fail-safe on power loss, at the cost of 8 W of coil power all the time.
3. **Independent hardware trip** (D8). A comparator with its own latch opens a relay in series with the microcontroller's valve switch, so a firmware bug cannot hold the valve open.
4. **Continuous ventilation with a boost** (D4). Avoids switching a motor on in a flammable mixture and proves fan rotation before gas can flow.
5. **Set points 10 % LFL (warn) and 25 % LFL (trip)** (D2). More conservative than the 25 % and 50 % levels often used in industry.
6. **24 V DC throughout, with a certified plug-in supply** (D9).
7. **Key-switch reset** (D6). Stops students from clearing a trip without a supervisor.
8. **One detector head per room** (D6). A second head is an option where the ceiling has beams or pockets, or where leak points are far apart (see Key numbers).
9. **Timed escalation** (HGD-DDR-002). A warning held for 5 min closes the valve and latches. Options were (a) this; (b) a lower trip at 20 % LFL; (c) warning only for small leaks. Decided: (a).
10. **Head placement rule** (HGD-DDR-002). A head directly above each likely leak point, with the horizontal offset limit set from the plume width at TRL 4. On 2026-10-02 Amish decided that the head hangs from the ceiling on a drop rod directly over the apparatus; wall mounting is allowed only if the TRL 4 plume test shows a trip at the wall position.

Decided by Amish on 2026-10-02 (HGD-DEC-001):

- **Airflow proven by a differential pressure switch** at the fan, as well as the tachometer. The switch reads the depression in the fan inlet against the room, which falls to about zero whether the fan stops, the duct is blocked or the shutter sticks.
- **A valve rated for hydrogen with a stated seat leak rate.** The low-cost brass valve is accepted only if its maker states hydrogen compatibility and a seat leak rating and it passes a seat leak proof test at TRL 4.
- **Oxygen sensor** as a standard kit option whenever inert gas cylinders share the room.
- **Set points** from the stricter of the national code and ISO 26142, and from the host institution's safety office where its rules are stricter; 10 % and 25 % LFL stay the defaults.
- **Full-span bump test** with 1 % hydrogen that trips the system; the pass level is set once the cup delivery factor is measured.
- **Dry-contact relay output** that opens on a trip or loss of power, for H2Bench to cut its own supply.
- **Clear-lid IP65 controller box**, so the lights and display show without opening it.
- **Fan motor in the sleeve** for the supervised teaching prototype only; a fan with its motor outside the air stream for any room used without close supervision.

## Relation to other lab projects

- **H2Bench** is the first host. Its README states that it is "Protected by H2Guard", and its gas system (electrolyzer, low-pressure store, regulator and tubing) is where the valve and any flow restrictor go. The inventory rule (R9, D5) applies to H2Bench's storage; its 2 L tank at 300 kPa gauge holds 7.9 L, 2.6 % of the limit. H2Bench's review asks for interlock outputs to cut its power supply and close its tank solenoid; H2Guard now has a dry-contact relay output that opens on a trip or loss of power, for H2Bench to cut its own supply (decided 2026-10-02); H2Bench still has to wire it into its supply.
- H2Guard does not use a SwapCell pack or any lithium cell, and it does not depend on FieldNode, CellGuard, MotionCore, ThermaCart, TwinKit or CalRig.

## Safety

> **Safety:** Hydrogen is flammable in air from about 4 % to 74 % by volume and ignites with very little energy. H2Guard is a research and teaching prototype, not a certified gas detection system, and it must not be the only safeguard in any room where codes or insurers require certified detection. Use certified equipment for any real installation.

> **Safety:** The parts are not certified for hazardous areas. The catalytic sensor element runs hot, and the fan motor, relays and supply are possible ignition sources. The motor in the exhaust sleeve is accepted only for the supervised teaching prototype; a room used without close supervision needs a fan with its motor outside the air stream. The design limits this by keeping the controller and supply low on the wall, running the fan continuously and fitting flame arrestors to the sensor ports, but it does not remove the risk.

> **Safety:** The design leak assumes a flow restrictor. A failed regulator on an unrestricted high-pressure cylinder can release gas far faster than the fan can remove it. Keep inventories within the R9 limit (300 L at atmospheric pressure for the 30 m3 room) or fit a restrictor, and have gas fittings made and leak-tested by a competent person.

> **Safety:** Catalytic sensors need oxygen and can be poisoned by silicones, sulfur compounds and some solvents, which makes them read low without warning. Bump test before each teaching session and after any exposure to these vapors, and replace the sensor when it fails a bump test. An oxygen-poor room makes the catalytic sensor read low, so fit the oxygen sensor option whenever inert gas cylinders share the room.

> **Safety:** The pressure switch now detects a blocked duct or a stuck shutter, but a leaking valve seat is still not detected in operation (HGD-CAL-001, Table 4). It is covered by the valve's stated hydrogen and seat leak ratings and by a seat leak proof test at TRL 4; until that test is done, check that the valve closes at every session, and prove the pressure switch at commissioning by covering its inlet tap.

> **Safety:** Mains power enters only through a certified plug-in supply. Do not open it or wire mains inside the controller.

## Open questions

- Confirm t90, power and poisoning behavior of the chosen catalytic sensor from its datasheet, and whether its hydrogen output gives 1 % LFL resolution (R1, R4).
- Measure the delivery factor of the open bump test cup and set the bump test pass level (the 1 % full-span test trips the system, decided 2026-10-02).
- Airflow proving, the valve, set point sources and oxygen monitoring were decided on 2026-10-02 (listed under the key design choices; HGD-DDR-001, O2 to O5).
- The horizontal offset limit for the head placement rule, from a measured plume width (TRL 4, on hold).

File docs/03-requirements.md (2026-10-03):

---
doc_id: HGD-REQ-001
title: H2Guard requirements
project: H2Guard
doc_type: Requirements
version: "0.7"
status: Draft
date: '2026-10-02'
author: Amish Chadha
license: CERN-OHL-S-2.0
revisions:
- version: "0.1"
  date: '2026-09-25'
  author: Amish Chadha
  change: Initial scaffold
- version: "0.2"
  date: '2026-09-25'
  author: Amish Chadha
  change: First measurable requirements for TRL 2, with status against the concept estimates
- version: "0.3"
  date: '2026-09-25'
  author: Amish Chadha
  change: TRL 3 status from HGD-CAL-001; set points and inventory rule adopted for TRL 3 per HGD-DDR-001 (pending Amish's review); R6 names the series relay and hardware latch; R12 names the bump test cup and port
- version: "0.4"
  date: '2026-09-25'
  author: Amish Chadha
  change: Recommendations accepted by Amish (DDR-002); R1 placement rule, R3 timed escalation, R13 scope and R14 budget restated; status from HGD-CAL-001 v0.2
- version: "0.5"
  date: '2026-10-01'
  author: Amish Chadha
  change: Design for construction (HGD-DDR-003); R13 and R14 status from HGD-CAL-001 v0.3; R14 reported against the value-engineering target
- version: "0.6"
  date: '2026-10-02'
  author: Amish Chadha
  change: R1 placement and R5 airflow proving from the decisions of 2026-10-02 (HGD-DEC-001); set point source rule
- version: "0.7"
  date: '2026-10-02'
  author: Amish Chadha
  change: Status from HGD-CAL-001 v0.4 after the decisions were carried into the model and BOM; R1 placement met on the drop rod, R5 with the pressure switch, R13 not met on estimate (5.0 h), R14 USD 411
---

# H2Guard requirements

These are first-pass requirements for the concept. Targets are proposals for review, not user-validated needs, and will be revised after sessions with the first users. At TRL 3 each requirement is checked by calculation in HGD-CAL-001 v0.4 against the design in HGD-PRC-001 v0.7, the constructable model in `cad/src/model.py` (HGD-DDR-003, with the decisions of 2026-10-02 carried in) and the build plan HGD-BLD-001. One requirement is **not met on its estimate**: R13 (installation, 5.0 h against 4 h, after the drop rod, pressure switch and their cables were added). Two are at risk: R4 (assumed sensor t90) and R7 (assumed fan curve). R14 is reported against the value-engineering target: the constructable design is estimated at USD 411, USD 146 over the USD 265 target. R1 cannot be verified without sensor data. On 2026-09-25 Amish accepted the review recommendations (HGD-DDR-002): R1 gains the head placement rule, R3 gains the timed escalation, R13 excludes the fan and grille wall openings as builder's work, and R14 follows the USD 265 figure, which is a value-engineering target, not a limit (Amish, 2026-10-01). The set points (R2, R3) and the inventory rule (R9) are decided by Amish (HGD-DDR-001, D2 and D5).

Table 1. Requirements. LFL is the lower flammability limit of hydrogen in air, taken as 4.0 % by volume, so 10 % LFL is 0.4 % vol and 25 % LFL is 1.0 % vol. Tags in brackets refer to lines of HGD-CAL-001.

| ID | Requirement | Target | Verification (TRL 3 or later) | Status at TRL 3 (HGD-CAL-001) |
| --- | --- | --- | --- | --- |
| R1 | Measure hydrogen at the high point of the room | 0 to 100 % LFL (0 to 4 % vol), resolution 1 % LFL or better; head within 0.3 m of the ceiling and directly above each likely leak point, with a second head where leak points are far apart; the horizontal offset limit is set at TRL 4 from the measured plume width | Sensor datasheet review; installation rule in the precis; offset limit by test at TRL 4 | **Not verifiable at TRL 3:** resolution needs sensor data; height met (ports 175 mm below the ceiling [L1]); plume radius about 141 mm at the ports [E7]. Placement met: the head hangs from the ceiling on a drop rod with its ports 0 mm from the apparatus centre, inside the plume (decided 2026-10-02; the former wall position, 260 mm off, did not meet the rule) |
| R2 | Warn early | At 10 % LFL (0.4 % vol): fan to boost, amber light, intermittent sounder; self-clearing | Set point and logic review | Met on paper: design leak plume at the head about 15 % LFL [E2] |
| R3 | Trip and shut off the supply | At 25 % LFL (1.0 % vol): valve closed, fan on boost, continuous sounder and beacon; latched until reset with a key and the reading is below 10 % LFL. A warning held for 5 min also closes the valve and latches in the same way (firmware rule) | Set point and logic review | Met by design: on the plume axis the design leak trips (about 30 % LFL [E2]); off the axis the escalation closes the valve at 5.6 min with 28 L released [F7] |
| R4 | Respond fast enough | Sensor t90 of 30 s or less; alarm within 60 s of a step to 1.1 % vol (twice t90, following the ISO 26142 test approach); valve closed within 2 s of the trip | Datasheets, then a bench test at TRL 4 | **At risk:** 35.7 s leak to valve closed with an assumed 30 s t90; 0.17 s trip to valve closed [F3, F4] |
| R5 | Fail safe | The supply is closed within 2 s of any of: loss of 24 V power, sensor open or short circuit, heater failure, controller watchdog timeout, fan stopped (no tachometer pulses for 10 s), airflow not proven by the differential pressure switch at the fan (added 2026-10-02) | Failure modes and effects analysis (FMEA) | Met on paper: worst listed fault 1.12 s, airflow loss included [F6]; the pressure switch on a fan inlet tap detects a blocked duct or stuck shutter [G6]. Three dangerous undetected faults remain (HGD-CAL-001 Table 4): two covered by the bump test, and the leaking valve seat covered by the valve's hydrogen and seat leak ratings and the TRL 4 proof test |
| R6 | Trip without firmware | A hardware comparator on the catalytic sensor bridge, with its own latch, opens a relay in series with the microcontroller's valve switch at the trip level, even if the microcontroller has stopped | Circuit review | Met by design (block diagram level) |
| R7 | Ventilate the room | Continuous exhaust at high level of 5 air changes per hour or more (150 m3/h for the 30 m3 reference room); boost of 10 air changes per hour or more; make-up air at low level on the far side | Fan curve against duct and grille losses | **At risk:** 347 m3/h boost with the re-specified fan on an assumed curve; the TRL 2 fan gave 237 m3/h [G3] |
| R8 | Keep the design leak below the trip level | With the design leak of 5 L/min and continuous ventilation, the well-mixed room stays below 10 % LFL | First-order dilution calculation | Met on paper: 5.0 % LFL well mixed and in the upper layer [D1, D3] |
| R9 | Limit what can leak | Hydrogen inventory that could be released into the room is 1 % of room volume or less at atmospheric pressure (300 L for 30 m3), unless a flow restrictor limits release to the design leak | Installation rule and host project review | Met by design as an installation rule; H2Bench's tank is 2.6 % of the limit; a 0.13 mm orifice at 10 bar gauge limits a failure to 5 L/min [B3, B4] |
| R10 | Alert people | Sounder 85 dB(A) or more at 1 m and a red beacon visible from the room entrance | Component ratings | Met on paper: 90 dB at 1 m, 76 dB at 5 m [K2] |
| R11 | Keep mains out of the self-built parts | All self-built wiring 24 V DC; mains only inside a certified power supply; power draw 60 W or less | Design review | Met on paper: 48.7 W peak in the warning state, 49.2 W with the oxygen sensor option [H2, H3] |
| R12 | Be checkable in use | Bump test with 1 % vol hydrogen span gas through the test port and head cup in 2 min or less; self-test button runs the alarm, fan boost and valve close; event log of readings, warnings, trips and resets kept for 90 days or more | Design review | Met on paper: bump reading settles in about 67 s [J1]; log 2.07 MB in 4 MB of flash [J3]; cup delivery factor unknown, so the pass level is set at TRL 4 |
| R13 | Install simply | Mounted and wired by one person with hand tools in 4 h or less, excluding the gas fitting, which a competent person makes, and the wall openings for the fan and make-up grille, which are builder's work | Task time estimate; walk-through at TRL 4 | **Not met on estimate:** 5.0 h, 60 min over [M1] (6.9 h if the openings were included); was at risk (4.2 h) at v0.6 |
| R14 | Cost against the value-engineering target | Value-engineering target USD 265 (`budget_usd`, a hypothetical control target) | Priced BOM | Over the value-engineering target by USD 146: estimated cost of the constructable design USD 411 [N1] on indicative prices; options (oxygen sensor, alternative fan) priced separately [N3] |
| R15 | Avoid adding ignition sources in the ceiling layer | Fan never switched on in a flammable mixture (runs continuously); controller, relays and power supply mounted at least 1 m below the ceiling; sensor ports behind sintered flame arrestors | Design review | Met by design: controller top 1,025 mm below the ceiling [L2]; **not certified** for hazardous areas, and the catalytic element runs hot |

## Assumptions

- Reference room: 4 x 3 x 2.5 m (30 m3), one door, general ventilation unknown and taken as zero.
- Design leak: 5 L/min of hydrogen, representing a failed fitting downstream of a regulator with a flow restrictor. A small electrolyzer of about 100 W makes only about 0.39 L/min (HGD-CAL-001, B1), so this covers it with margin. A failed regulator on an unrestricted cylinder can release far more, and H2Guard does not protect against that (R9).
- Hydrogen rises from the leak as a buoyant plume and collects under the ceiling. HGD-CAL-001 uses plume theory for the head and a well-mixed or displacement model for the room.
- Set points follow common practice for hydrogen detection (warning at 10 % LFL, shutdown at 25 % LFL); ISO 26142 describes alarm levels at 25 % or 50 % LFL. The set points are decided by Amish, 2026-09-25 (HGD-DDR-001, D2). On 2026-10-02 Amish decided that each site takes its set points and inventory rule from the stricter of the national code and ISO 26142, and from the host institution's safety office where its rules are stricter; 10 % and 25 % LFL stay the defaults.
- Value-engineering target: the USD 265 in `project.yaml` (raised from USD 180 by Amish's acceptance of the recommendation, HGD-DDR-002) is a hypothetical control target, not a limit. It covers the H2Guard kit including the fan and make-up grille, but not the gas system, span gas, wall openings or installation labor.

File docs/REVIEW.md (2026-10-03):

# Review note: H2Guard

## Session 2026-09-25: /populate to a strong TRL 2

### What was done

- `docs/01-problem.md` (HGD-PRB-001 v0.2): problem with cited hydrogen properties, adoption figures and incidents; users; operating environment; constraints; out of scope; prior work (ISO 26142, NFPA 2, sensor types, HIAD 2.0); open questions. There was no co-design checklist to keep.
- `docs/03-requirements.md` (HGD-REQ-001 v0.2): 15 measurable requirements (R1 to R15) with targets, verification method and status at TRL 2, plus assumptions.
- `docs/02-concept.md` (HGD-PRC-001 v0.2): how it works, 12 numbered components, first-order numbers (electrolyzer output, ceiling layer build-up, dilution, response time, inventory limit, power, cost), eight design choices, relation to H2Bench, safety, open questions.
- `cad/src/concept_media.py`: massing model of a 30 m3 class teaching room with the 12 H2Guard parts colored and numbered, and grey context (room, bench, apparatus, small cylinder, supply line, cable runs, 1.75 m person).
- `media/`: `hero.png`, `concept-blueprint.png`, `.pdf` and `.svg` (orthographic views include the room outline so heights read correctly), `model.glb` and `viewer.html`, `exploded.png` (compact kit-of-parts layout with BOM callouts), `cutaway.png` (sections through controller and detector head), `flow.png` (detect, decide, act chain with estimated values). Temporary `_views` folders removed.
- `bom/bom.csv`: 14 lines with indicative prices, lines 1 to 12 matching the exploded view; `bom/bom-notes.md` updated.
- `README.md`: hero image and links line; Concept rationale, Burning platform, By industry and By country or region tables, and What sparked the idea expanded with cited figures; Concept, Key components and Safety brought in line with the precis.
- `docs/pdf/`: branded PDFs of the three controlled documents.

`project.yaml` is unchanged: the pitch and problem still match the numbers found.

### Key results (estimates, to be checked at TRL 3)

| Quantity | Estimate | Requirement |
| --- | --- | --- |
| Warning and trip set points | 10 % LFL (0.4 % vol) and 25 % LFL (1.0 % vol) | R2, R3 by design |
| Hydrogen from a 100 W electrolyzer | about 0.4 L/min | Design leak 5 L/min covers it |
| Ceiling layer (0.3 m) to 25 % LFL, 5 L/min, no ventilation | about 7 min (whole room mixed: about 60 min) | |
| Well-mixed concentration, 5 L/min leak, 150 m3/h exhaust | about 0.20 % vol (5 % LFL) | R8 met by estimate |
| Leak reaching head to valve closed | about 35 s (sensor t90 30 s assumed) | R4 unverified |
| Hydrogen released before the valve closes | about 3 L | |
| Inventory limit for a 30 m3 room | 300 L at atmospheric pressure (about 25 g) | R9 proposed |
| Power | about 21 W normal, 29 W in alarm | R11 met |
| Parts cost | about $239 (about $196 without fan and grille) | **R14 not met** |

Requirements not met or unverified:

- **R14 (cost) not met:** about $239 against $180.
- **R12 (bump test in use) not met:** no test cap or span gas port is designed yet.
- **R4 unverified:** the t90 of the proposed catalytic sensor has not been confirmed from a datasheet.
- **R7 unverified:** fan rated about 300 m3/h in free air; duct, grille and hood losses not yet checked.
- **R15 not certified:** layout avoids ignition sources in the ceiling layer, but no part is rated for hazardous areas.
- R5 and R6 (fail-safe and hardware trip) are met by design only; no FMEA yet.

### Proposed, awaiting Amish

Status update 2026-09-25: items 1 to 8 are decided by Amish, 2026-09-25: go with recommendation (HGD-DDR-001, HGD-DDR-002). For item 1 the later TRL 3 recommendation ($265) superseded the $250 figure.

1. **Budget.** Options: (a) raise `budget_usd` to $250; (b) treat the fan and grille as site ventilation outside the kit, giving about $196, still over; (c) drop the metal oxide sensor and use a cheaper enclosure and valve to approach $180, losing early warning. Recommendation: (a). `project.yaml` is unchanged. Decided by Amish, 2026-09-25: go with recommendation, as revised at TRL 3 to $265.
2. **Sensor baseline.** Options: (a) catalytic plus metal oxide pair (about $50); (b) certified MPS sensor (about $249, total about $440); (c) metal oxide only. Recommendation: (a) for supervised teaching, with (b) documented as the upgrade. Decided by Amish, 2026-09-25: go with recommendation.
3. **Set points** of 10 % LFL warning and 25 % LFL trip, more conservative than the 25 % and 50 % levels common in industry. Recommendation: keep. Decided by Amish, 2026-09-25: go with recommendation.
4. **Normally closed valve, energize to open**, rather than a latching or motorized valve. Recommendation: keep. Decided by Amish, 2026-09-25: go with recommendation.
5. **Continuous ventilation with boost**, rather than a fan that starts on alarm. Recommendation: keep. Decided by Amish, 2026-09-25: go with recommendation.
6. **Inventory rule (R9):** 1 % of room volume at atmospheric pressure, or a flow restrictor sized to the design leak, as a condition for H2Bench and any other lab project using H2Guard. Recommendation: adopt, and ask H2Bench to reflect it. Decided by Amish, 2026-09-25: go with recommendation.
7. **Key-switch reset and one detector head per room** as the base kit, with a second head as an option. Decided by Amish, 2026-09-25: go with recommendation.
8. **First users:** a school science department running H2Bench, a university teaching lab or a startup. Recommendation: a university teaching lab first, because supervision and a technician are in place. Decided by Amish, 2026-09-25: go with recommendation.

### Safety concerns

- It is a teaching prototype, not certified detection; the documents say this plainly, but a low-cost kit invites use as the only safeguard.
- Ignition sources: the catalytic element runs hot, and the fan motor and relays are not rated for flammable atmospheres.
- An unrestricted high-pressure cylinder can overwhelm any small fan; the inventory rule and flow restrictor are essential.
- Catalytic sensors are poisoned by silicones and some solvents and then read low; bump testing is needed, and the means of doing it is not designed yet.
- Mains appears only inside a certified plug-in supply.

### Problems and notes

- The kit's `cutaway_parts` places its cutter box at X = 0, Z = 0, so it misses parts far from the origin. `concept_media.py` therefore cuts the head and controller with its own function. This may affect other repos with large scenes; worth fixing in the kit.
- `render_all` was run with `cut=False` and `scale_figure=False` (the person is added as a context part so it stands clear of the wall); the hero and blueprint are then re-rendered in the script with clearer notes and room context in the orthographic views.
- The legacy `cad/src/model.py` placeholder is untouched (TRL 3 work).
- Suggestion only: CalRig could add a hydrogen span gas check; that is CalRig's decision.

### Recommended next step

Review this note and the media, then decide items 1, 2 and 6. If approved, run `/advance-trl3` to confirm the sensor data, calculate the ventilation with duct losses, write the FMEA of the trip chain, design the bump test port and produce the parametric model and drawing sheet.

## Session 2026-09-25: TRL 3

On 2026-09-25 Amish asked for this batch of repos to be taken through the usual process with the instruction "you know the drill, nothing gets past TRL 3". He has not reviewed the H2Guard TRL 2 points item by item, so every item with a recommendation is adopted as recommended for TRL 3 under Amish's 2026-09-25 instruction, open for his review. This session ran `/advance-trl3` on that basis and stopped at TRL 3.

### What was done

- `docs/decisions/0001-trl2-review-decisions.md` (HGD-DDR-001 v0.1, status proposed): nine items adopted as recommended for TRL 3, open for Amish's review (D1 to D9), and five items left open (O1 to O5), including the budget figure.
- `docs/04-calcs/01-sizing.md` (HGD-CAL-001 v0.1) and `docs/04-calcs/sizing.py` (writes `docs/04-calcs/results.txt`): sources and inventory, flow restrictor sizing, build-up, dilution, the plume at the detector head, arrestor lag, the response and fault chain, fan and duct losses, power, bump test and log, alarm level, placement, installation time, cost, and a first-pass FMEA of the trip chain, with a status for every requirement. The script imports the model's parameters and reads the BOM and `project.yaml`.
- `cad/src/model.py`: parametric build123d model of all H2Guard parts in the 30 m3 reference room (head with ports, sensors, arrestors and bump test cup; controller, board and panel; supply; fan with grille, sleeve and hood; make-up grille; valve; beacon; bump test port and tube) plus grey context. Exports `cad/step/` and `cad/stl/` for `h2guard-assembly`, `detector-head`, `controller` and `exhaust-fan`.
- `cad/src/sheets.py` and `cad/drawings/HGD-DWG-001.svg`, `.pdf`, `.png`: general arrangement at Rev P1, 1:50, with mounting heights, a detector head detail and interface notes, marked "CONCEPT, NOT FOR FABRICATION" and "PRELIMINARY, NOT FOR FABRICATION". HGD-DWG-001 was free because the concept blueprint is HGD-DWG-010 (now Rev P2 from the model).
- `bom/bom.csv` (15 lines, all priced with a supplier type, $264.00) and `bom/bom-notes.md`.
- `cad/src/concept_media.py` now builds from the model; all of `media/` was re-rendered and every image checked (the person was moved clear of the controller and callout 15 clear of the panel). Temporary `_views` folders removed.
- HGD-PRB-001, HGD-PRC-001 and HGD-REQ-001 revised to v0.3; `README.md` (TRL 3, cost, findings, links) and `project.yaml` (`trl: 3`, `trl_target: 3`, evidence list) updated. PDFs rebuilt in `docs/pdf/`.

Design changes the calculations required, within the adopted choices: the exhaust fan is re-specified from a 300 m3/h axial fan (237 m3/h against the losses) to a 450 m3/h mixed-flow EC fan (347 m3/h); the arrestor discs are 2 mm instead of 5 mm with the sensors about 2 mm behind them (lag 1.5 s instead of about 21 s); a bump test cup, tube and capped port are added (R12); the comparator trip now has a hardware latch and a relay in series with the microcontroller's valve switch; the board needs 4 MB of flash for the 90-day log; the reference room in the model is the 4 x 3 x 2.5 m room of the requirements (the TRL 2 media used a 2.6 m ceiling).

### Requirement status (HGD-CAL-001, Table 5)

2 not met, 2 at risk, 1 not verifiable at TRL 3, 6 met on paper, 4 met by design.

| ID | Status | Key number |
| --- | --- | --- |
| R14 Cost | **Not met** | $264.00 against $180; also $14 over the $250 recommended at TRL 2 |
| R13 Installation | **Not met** on estimate | 6.0 h (4 h limit); 4.1 h if the wall openings are made by others |
| R4 Response | At risk | 35.7 s leak to valve closed with an assumed 30 s t90; 0.17 s trip to closed |
| R7 Ventilation | At risk | 347 m3/h boost on an assumed fan curve (target 300); the TRL 2 fan gave 237 |
| R1 Measurement | Not verifiable at TRL 3 | Resolution needs sensor data; ports 175 mm below the ceiling |
| R2, R5, R8, R10, R11, R12 | Met on paper | Plume 15 % LFL at the head; worst listed fault 1.12 s; room 5.0 % LFL; 76 dB at 5 m; 48.3 W peak; bump test 67 s |
| R3, R6, R9, R15 | Met by design | Latched trip; series hardware relay; 300 L inventory rule (H2Bench 2.6 % of it); controller 1,025 mm below the ceiling |

Key numbers: electrolyzer 0.39 L/min; design leak plume at the head about 15 % LFL mean and 30 % LFL on the axis; 3.0 L released before the valve closes; restrictor orifice 0.13 mm at 10 bar gauge; 13.1 W normal power.

### Decisions recorded (HGD-DDR-001)

Adopted as recommended for TRL 3 under Amish's 2026-09-25 instruction, open for his review: D1 catalytic plus metal oxide sensors, certified sensor as the upgrade; D2 set points 10 % and 25 % LFL; D3 normally closed valve; D4 continuous ventilation with boost; D5 inventory rule (R9); D6 key-switch reset and one head per room, second head optional; D7 a university teaching lab as first users; D8 independent hardware trip; D9 24 V DC with a certified supply. No pitch or problem rewording was recommended, so none was applied.

### Still awaiting Amish

1. **O1, budget.** The TRL 2 recommendation was to raise `budget_usd` to $250; `budget_usd` is unchanged at $180. The priced BOM is $264, over both. Options: (a) $265, covering the TRL 3 kit; (b) $250 with the fan and grille treated as site ventilation ($206 kit); (c) keep $180 and accept R14 not met. Recommendation: (a), because the fan is part of the safety function. Decided by Amish, 2026-09-25: go with recommendation ($265).
2. **O2 to O5.** Oxygen depletion monitoring; set points and inventory rules per country; airflow proving (tachometer only or a differential pressure switch); low-cost or certified gas valve. No recommendations were made. Still proposed, awaiting Amish.
3. **New, timed escalation.** The design leak trips the system only on the plume axis; beside it, or for leaks under about 3.8 L/min, the head warns without closing the supply (HGD-CAL-001, E). Options: (a) close the valve when a warning persists for 5 min; (b) lower the trip to 20 % LFL; (c) accept warning-only for small leaks. Recommendation: (a). Decided by Amish, 2026-09-25: go with recommendation; applied (see the session below).
4. **New, head placement rule.** Keep the head directly above each likely leak point, within a horizontal distance to be set from the plume width, with a second head where leak points are far apart. Recommendation: adopt with the distance set at TRL 4. Decided by Amish, 2026-09-25: go with recommendation; rule applied, distance on hold with TRL 4.
5. **New, R13 scope.** Options: (a) keep 4 h including the wall openings (not met); (b) exclude the fan and grille openings as builder's work (4.1 h, at risk). Recommendation: (b). Decided by Amish, 2026-09-25: go with recommendation; applied.
6. **New, bump test and trip.** A full-span 1 % vol bump test trips the system. Options: (a) keep, as a proof test of the whole chain, with a key reset after each test; (b) use a lower span gas, for example 0.5 % vol. No recommendation until the cup delivery factor is known. Still proposed, awaiting Amish.

### Cross-repo notes

- H2Guard does not depend on FieldNode, CellGuard, MotionCore, ThermaCart, TwinKit or CalRig, so no shared interface applies. CalRig hosting a hydrogen span check remains a suggestion for CalRig.
- H2Bench (host project, read only): its review lists an H2Guard interlock that cuts its bench power supply and closes its tank solenoid, with set point and response time undefined. H2Guard now defines both (25 % LFL; 0.17 s trip to closed) but has one 24 V valve output. A second output, a dry contact for the bench supply, is not in the design; this is an interface point for Amish and H2Bench, not edited here. H2Bench's 7.9 L inventory is within the adopted R9 rule.

### Safety concerns

- False reassurance: a low-cost kit invites use as the only safeguard. The documents say it is a research and teaching prototype, not a certified gas detection system.
- Small or off-axis leaks can hold the head in the warning band with the supply open (new proposal 3).
- Four dangerous undetected faults (HGD-CAL-001, Table 4): blocked duct with the fan turning, poisoned sensor, blocked port and a leaking valve seat. Bump tests cover two; airflow proving and a valve proof test are not designed.
- Ignition sources: the catalytic element runs hot and no part is rated for hazardous areas; the fan motor sits in the exhaust stream.
- An unrestricted high-pressure cylinder overwhelms the fan; the restrictor and inventory rule are essential. Mains appears only inside a certified supply.

### Gaps and notes

- Citations: WebSearch was exhausted. A WebFetch of the Figaro TGS6812 product page was not approved in time; the cited Figaro 2025 overview PDF was fetched and says only that the TGS6812 detects hydrogen up to 100 % LEL with a "fast response", so the sensor t90, power and output remain unconfirmed. No other citation was flagged as unchecked at TRL 2.
- Assumptions only tests can settle: sensor t90 and sensitivity, fan curve, duct losses, plume axis factor and cup delivery factor. Installation times are judgment.
- The exploded view's MOS sensor (3) is too small to see at that scale; its callout marks its position.
- The kit's cutaway cuts only near the origin; `concept_media.py` keeps its own cut function (as at TRL 2). Worth fixing in the kit.
- Existing material beyond TRL 3: `build-log/README.md` (scaffold) is present, untouched and not extended. No test, build, purchasing or firmware material exists.

### Recommended next step

Review HGD-DDR-001 and decide O1 and the four new proposals, above all the timed escalation (item 3), which changes how the system responds to small leaks. TRL 4 is on hold by Amish's instruction; nothing further should be built or tested. For reference only, TRL 4 would need: sensor datasheet confirmation and a bench test of t90 and resolution; a fan curve test against the real duct and grille; a measured bump cup delivery factor; a lab-built controller with the hardware trip exercised against every fault in Table 4; a TST report with `environment: lab`; and build log entries.

## Session 2026-09-25: recommendations accepted

On 2026-09-25 Amish wrote: "i accept all your recommendations, go with them across all repos." Every item with a recommendation is now decided by Amish, 2026-09-25: go with recommendation. The record is `docs/decisions/0002-recommendations-accepted.md` (HGD-DDR-002 v0.1); HGD-DDR-001 is revised to v0.2 with D1 to D9 and O1 marked decided.

### Decisions applied and what changed

| Item | Decision | Before | After |
| --- | --- | --- | --- |
| Budget (TRL 2 item 1, O1) | $265, covering the TRL 3 kit with fan and grille | `budget_usd` 180; R14 not met, $264 is +47 % | `budget_usd` 265; R14 met on paper, $1 margin |
| Timed escalation | A warning held 5 min closes the valve and latches (firmware rule) | Off-axis design leak warned but never closed the supply | Valve closed at 5.6 min, 28 L released (9 % of the R9 limit), room about 1.9 % LFL [F7, F8]; R3 restated |
| Head placement rule | Head directly above each likely leak point; second head where leak points are far apart; offset limit at TRL 4 | Rule proposed only | R1 restated; plume radius 141 mm at the ports as the paper basis [E7]; offset limit on hold with TRL 4 |
| R13 scope | Fan and grille wall openings are builder's work | Target included openings: 6.0 h, not met | Target excludes them: 4.1 h, at risk (5 min over) |
| D1 to D9 | As recommended (sensor pair, set points, NC valve, continuous ventilation, inventory rule, key reset and one head, university teaching lab first, hardware trip, 24 V DC) | Adopted for TRL 3, open for review | Decided; wording only |
| H2Bench to reflect the inventory rule | Adopt | Asked through the review note | Listed below as a cross-repo action |

Files changed: `project.yaml` (budget, evidence list), `README.md` (budget, concept, key components, decisions links, What sparked the idea), HGD-PRB-001 v0.4, HGD-PRC-001 v0.4, HGD-REQ-001 v0.4, HGD-CAL-001 v0.2 (`sizing.py` adds E7, F7 and F8 and reads the new budget; `results.txt` regenerated), HGD-DDR-001 v0.2, new HGD-DDR-002, `bom/bom-notes.md`, HGD-DWG-001 Rev P1 to P2 (two new notes: placement rule and timed escalation), concept blueprint HGD-DWG-010 Rev P2 to P3 (key figures). No part was added or resized, so `bom/bom.csv` ($264.00) and the model geometry are unchanged; `cad/src/model.py` was re-run and STEP and STL re-exported. No pitch or problem rewording was recommended.

All PDFs, drawings and media were regenerated so that no generated file still shows the old personal domain. `README.md` "What sparked the idea" now traces the design to the 1937 New London School explosion and the odorization law that followed, since hydrogen cannot be odorized (OSHA); the earlier text about a portfolio review was removed.

### Requirement status now (HGD-CAL-001 v0.2, Table 5)

0 not met, 3 at risk, 1 not verifiable at TRL 3, 7 met on paper, 4 met by design (before: 2 not met, 2 at risk, 1, 6, 4).

| ID | Status | Key number |
| --- | --- | --- |
| R13 Installation | At risk | 4.1 h against 4 h, wall openings excluded |
| R4 Response | At risk | 35.7 s leak to valve closed with an assumed 30 s t90 |
| R7 Ventilation | At risk | 347 m3/h boost on an assumed fan curve |
| R1 Measurement | Not verifiable at TRL 3 | Resolution needs sensor data; placement rule adopted |
| R2, R5, R8, R10, R11, R12, R14 | Met on paper | R14: $264.00 against $265 |
| R3, R6, R9, R15 | Met by design | R3 now includes the 5 min escalation |

### Still awaiting Amish (no recommendation was made)

- O2 oxygen depletion monitoring; O3 source of set points and inventory rule per country; O4 airflow proving (tachometer or differential pressure switch); O5 low-cost or certified gas valve.
- Whether a full-span bump test trips the system or a lower span gas is used (no recommendation until the cup delivery factor is known).
- A second interlock output (dry contact) for H2Bench's bench supply (interface point, no recommendation).

### Cross-repo actions

- **H2Bench:** reflect the decided R9 inventory rule (1 % of room volume at atmospheric pressure, or a flow restrictor sized to 5 L/min) in its gas system documents. Its 7.9 L tank is already within the rule. H2Bench was not edited.

### Safety

- The timed escalation is a firmware rule and is not independent like the comparator trip; a leak below about 2.7 L/min at the head gives no warning and is not escalated.
- The other safety concerns of the TRL 3 session stand: false reassurance from a low-cost kit, four dangerous undetected faults, ignition sources, and the need for the inventory rule or a restrictor.

### TRL 4

TRL 4 remains on hold by Amish's instruction. `trl: 3` and `trl_target: 3` are unchanged. Setting the head offset limit by test, the escalation firmware beyond a sketch, and all build, test and purchasing work are decided where recommended but not started.

## Session 2026-09-26: sources strengthened

Every README link in the four rationale sections was re-fetched with WebFetch and checked against its claim.

- **Namibia row:** the link to the Namibia Green Hydrogen Programme site loads and confirms a government program, but the row's second clause (local colleges may lack budgets for industrial detection) had no source. It was replaced with the NUST vice-chancellor's warning of a talent gap of up to 130,000 workers by 2040 (*The Namibian*, 21 September 2025) and NUST's own IGNITE GH2 page (685 graduates and 40 instructors). The row label is now "Namibia."
- **University of Hawaii fine (Burning platform, United States row and HGD-PRB-001):** C&EN alone replaced by C&EN plus the *Honolulu Star-Advertiser* (7 October 2016), which also reports that the 15 violations and $115,500 were later settled at nine violations and $69,300. The uncited clause "many teaching labs handle small gas quantities without fixed detection" was removed from the United States row. HGD-PRB-001 moved to v0.5.
- Confirmed unchanged: IEA Global Hydrogen Review 2025, US DOE hydrogen safety fact sheet, Korea Herald (Gangneung, 2019), Wen et al. (2022), OSHA 1910.178(g)(2), EU hydrogen strategy COM(2020) 301 (40 GW by 2030), PIB (National Green Hydrogen Mission), Texas State Historical Association (New London, 1937) and OSHA hydrogen fire and explosion page.
- No budget change.

## Session 2026-09-26: product appearance model and photoreal renders

Amish chose this repo for the first batch of product renders on 2026-09-26.

### What was added

`cad/src/product_model.py` exposes `product_parts()` (53 parts: 28 shell, 14 internal, 5 accessory, 6 context), `TITLE` and `RENDER_VIEWS` (hero, exploded and a detail view of the head and controller without context). It reuses PARAMS and derived() from `cad/src/model.py`; every part size, the head-to-ceiling gap, the offsets from the wall and the controller position are as model.py. It adds:

- Detector head: filleted housing with a parting line, wall plate and screws, cable gland, teal accent band and a printed label, the catalytic and MOS sensor cans on their carrier board, the sintered arrestor discs, and the filleted drip skirt and bump test cup with its nozzle.
- Controller: filleted IP65 box with side ribs, a lid frame with a clear polycarbonate window over the board, four lid screws, a teal name plate, cable glands, an OLED display with a lit readout, the key-switch reset, a teal test button and three status lights with the green one lit.
- Controller board: PCB, microcontroller module with its shield can, the series trip relay and the fan interlock relay and valve driver (in the model.py envelopes, with labels), terminal strip and screws.
- Bump test port with bracket and teal dust cap; the 4 mm tube.
- Normally closed solenoid valve: brass body with hex port fittings, coil with a label, and the coil connector.
- Context (not in the BOM): two wall panels, a ceiling section over the head, surface conduit, the hydrogen supply pipe and its stand-off clips.

`README.md` now shows `media/render-hero.png` and links `media/render-exploded.png`; the orchestrator produces both files.

### Differences from model.py (Proposed, awaiting Amish)

1. **Render layout of the head and valve.** In the reference room the head is 1.6 m and the valve 2.35 m from the controller along the wall, and the head ports are about 1.15 m above the controller top. At that spacing each device is too small in a product render. The appearance model therefore shows the head, with its own ceiling section, on a separate wall panel beside the controller panel, drawn 820 mm lower than installed, and the valve on the head panel below it. The head keeps its 85 mm gap to its ceiling and all sizes are unchanged. Proposed, awaiting Amish. Recommendation: keep this as a render-only layout, with the hero caption saying the panels are not at installed heights (the view note does); the installed heights stay as in model.py and HGD-DWG-001 (ports 175 mm below the ceiling, controller top at least 1 m below it). Option: render the true room layout instead, accepting small devices.
2. **Clear window in the controller lid.** BOM line 5 specifies an IP65 polycarbonate wall box without saying whether the lid is clear. The appearance model uses a lid frame with a clear polycarbonate window so the board and relays show, which suits a teaching prototype. Proposed, awaiting Amish. Recommendation: adopt a clear-lid IP65 box (common and similar in price) and add "clear lid" to BOM line 5 at the next BOM revision; it was not edited now.
3. **Omitted parts.** The exhaust fan, make-up air grille, sounder and beacon and power supply (BOM lines 8, 9, 10, 12) are not in the appearance model, to keep the render compact; they remain in model.py and the concept media. Proposed, awaiting Amish. Recommendation: accept for the product renders.
4. **Fixings and label detail.** Screws, glands, labels and the conduit are appearance detail, with BOM lines 13 and 14 for cable and hardware; no new BOM lines are implied.

### Status

This is an appearance model only: no tolerances, no fabrication detail, nothing past TRL 3. `trl: 3` and `trl_target: 3` are unchanged, and TRL 4 remains on hold. model.py, the BOM and the other documents were not edited.

## Session 2026-09-27: kit 1.5.0 and image quality

- Kit 1.5.0 synced: STANDARDS v1.5 (sections 12 to 15: product renders, storefront images and image quality, public release, authorship and signing), `.kit/cards.py`, `.kit/image_qc.py`, `.kit/release_gate.py`, issue templates, and the `/render-product` and `/release` commands. `CLAUDE.md` now matches `.kit/CLAUDE.md`.
- Every `media/render-*.png` recaptioned from its original render with the new layout: the title, concept label and repository sit in a band above the render and the view note in a band below it, each line wrapped to the image width, so no text overlaps other text or the render or runs off the image. `media/card.png` and `media/social-preview.png` regenerated with the same rules.
- `python .kit/image_qc.py` and `python .kit/release_gate.py` pass. trl stays 3.

## Session 2026-10-01: design for construction and prototype build plan (kit 1.7.0)

Kit 1.7.0 installed (`.kit/`, `.claude/commands/`, `CLAUDE.md`). On 2026-09-30 Amish asked for an illustrated build plan in every repo and wrote: "If you are realising that the design cannot be built as per concept - fix the design assumptions to match and be physically feasible as you draw the illustrations." The changes below were made under that instruction to make the design physically buildable; they are recorded in HGD-DDR-003 (status Draft) and are open for his review. None changes what H2Guard does, its pitch or its safety case.

### Design changes made for construction

`cad/src/model.py` now builds every part a maker handles, with its fixings, and runs 127 constructability checks (`python cad/src/model.py --check`, all pass).

1. Bump test cup: its solid top covered both sensor ports; two 22 mm openings added over the ports.
2. Arrestor discs: 25 mm discs in 26 mm ports would fall through; ports now 22 mm, discs rest on the ledge and are bonded with two-part epoxy (no silicone).
3. Detector head: the fused wall plate cut into the box and nothing held it; the plate is gone and two M4 screws through the back hold the stock box, lid facing the room.
4. Sensor board and cup: no fixing; four 22 mm M3 standoffs, screwed from below through the cup and from above through the board.
5. Cup nozzle: a solid stub; now an M5 push-in fitting for the 4 mm tube in a printed boss.
6. Controller board: floating, with modules cutting into it; now a 2 mm aluminium mounting plate on the box's four bosses with modules on 6 mm nylon standoffs.
7. Front panel: floating in front of an open box; now the box's own lid, cut for the display, key switch, button and lights.
8. Controller: five M16 cable glands and four corner wall screws added.
9. Bump test port: overlapped a solid block; now a 30 x 30 x 3 mm aluminium angle bracket with the port pointing down, and seven tube clips.
10. Exhaust fan: a 170 mm fan drawn as a 146 mm motor floating in a 150 mm sleeve; now a 200 mm sleeve with the fan held by a 3 mm aluminium fan plate on the inside wall, the grille screwed to the plate, shutter on the outlet spigot and a hood with fixing tabs. The air path is still 150 mm, so the fan delivery is unchanged.
11. Solenoid valve: hung in mid-air with the supply pipe through its body; now on a bent 40 x 5 mm flat-bar bracket with two M5 screws.

Knock-on: BOM lines 1, 2, 4, 5, 6, 7, 9, 11, 14 and 15 re-specified and line 16 (made brackets and plates) added. Re-run calculations (HGD-CAL-001 v0.3): bump test tube 2.72 m, reading still settles in about 67 s [J1]; installation 4.2 h, 15 min over R13 (still at risk) [M1]; estimated cost USD 289.00 against the USD 265 value-engineering target, USD 24 over [N1]. HGD-REQ-001 v0.5, HGD-PRC-001 v0.5, HGD-PRB-001 v0.6 and `bom/bom-notes.md` updated.

### What was added or regenerated

- `docs/05-build-plan.md` (HGD-BLD-001 v0.1) with `cad/src/build_plan_media.py`: overview, nine making sketches (`cad/drawings/HGD-DWG-101` to `109`), seven joint close-ups, fifteen assembly step pictures and a block-level wiring diagram in `docs/05-build-plan/`.
- `docs/06-design-decisions.md` (HGD-DEC-001 v0.1): 12 open decisions, 7 items to confirm when parts are bought, a value engineering section, and the decisions made.
- `docs/decisions/0003-design-for-construction.md` (HGD-DDR-003 v0.1, Draft).
- `cad/drawings/HGD-DWG-001` Rev P4; concept blueprint HGD-DWG-010 Rev P4; `media/hero.png`, `exploded.png`, `cutaway.png`, `flow.png`, `model.glb`, `viewer.html`; STEP and STL in `cad/step/` and `cad/stl/`.
- `project.yaml`: `design_state: constructable`, the three new documents in `trl_evidence`; `budget_usd` unchanged. `README.md`: links line, cost wording and a "Building the prototype" section.

### Proposed, awaiting Amish

- Accept the changes above (HGD-DDR-003, Table 1). Recommendation: accept.
- A1: the head stays on the back wall, 110 mm from the apparatus's back edge and 260 mm from its centre, against a plume radius of about 141 mm; the offset limit is a TRL 4 test. Recommendation: keep the wall mounting.
- A2: the fan motor now sits inside the wall sleeve in the exhaust stream. Recommendation: accept.
- All other open items are listed in the design decisions register.

### Stale media

The photoreal renders (`media/render-*.png`, made on Amish's Mac and not in this copy), `media/card.png` and `media/social-preview.png` show the concept head, controller and valve without the new brackets, fan plate and larger sleeve, and should be regenerated on the Mac. `cad/src/product_model.py` reads the new 22 mm port size from `model.py` but does not yet model the new brackets and plates.

### Safety

No new hazard is introduced. The build plan adds safety stops before power, before gas reaches the valve, before the first bump test and before hydrogen is used, and keeps silicone and solvents away from the sensors. The earlier concerns stand: false reassurance from a low-cost kit, undetected blocked ducts and leaking valve seats, ignition sources, and the need for the inventory rule or a restrictor.

### Recommended next step

Amish reviews HGD-DDR-003 and the register. TRL 4 (building and testing to the plan) remains on hold.

## Session 2026-10-02: open decisions decided

On 2026-10-02 Amish approved every recommendation written for the open decisions: "i approve your recommendations for all 555 open decisions." Nothing was built or tested; TRL 4 remains on hold.

### Decisions recorded

12 decisions moved from "Open decisions" to "Decisions made" in the design decisions register, dated 2026-10-02. Design for construction (HGD-DDR-003) accepted; the head moves to a ceiling drop rod directly over the apparatus (changed recommendation); fan motor in the sleeve for the supervised prototype only; oxygen sensor option, set point sources, differential pressure switch, hydrogen-rated valve, tripping bump test and dry-contact output added; render choices and a clear-lid controller box accepted. Nothing should be connected to gas until the follow-ups for decisions 2, 6 and 7 are carried into the design.

### Documents changed

- `docs/01-problem.md` (HGD-PRB-001 v0.7)
- `docs/02-concept.md` (HGD-PRC-001 v0.6)
- `docs/03-requirements.md` (HGD-REQ-001 v0.6)
- `docs/05-build-plan.md` (HGD-BLD-001 v0.2)
- `docs/06-design-decisions.md` (HGD-DEC-001 v0.2)
- `docs/decisions/0001-trl2-review-decisions.md` (HGD-DDR-001 v0.3)
- `docs/decisions/0002-recommendations-accepted.md` (HGD-DDR-002 v0.2)
- `docs/decisions/0003-design-for-construction.md` (HGD-DDR-003 v0.2)
- `README.md` (not a controlled document)
- `bom/bom-notes.md` (not a controlled document)
- `docs/pdf/`: every controlled document re-rendered.

### Follow-up actions to carry approved decisions into the design

The model, drawings, build plan pictures, BOM quantities and prices, and calculations were not changed in this session. These actions carry the approved decisions into them:

1. Decision 2 (model): Move the head in cad/src/model.py to a ceiling drop rod with its ports directly over the apparatus, 175 mm below the ceiling; re-run the constructability checks; re-export STEP and STL. Must be done before any gas is connected.
2. Decision 2 (drawings): HGD-DWG-001 and a making sketch for the drop rod and its ceiling plate; update the concept blueprint HGD-DWG-010.
3. Decision 2 (pictures): Build plan: rewrite step 4 and the head section for the drop rod and regenerate the overview, joint and step pictures; update the "Head over the leak point" check.
4. Decision 2 (calcs): HGD-CAL-001 E7 and the R1 row: recompute the port offset for the drop rod position (zero offset) and correct the placement status flagged in the review.
5. Decision 2 (bom): Add the drop rod, ceiling plate and fixings and price them.
6. Decision 3 (docs): State in the installation notes that a room used without close supervision needs a fan with its motor outside the air stream; specify that fan as an alternative BOM line.
7. Decision 4 (bom): Add the oxygen sensor as a standard kit option (sensor, cable, controller input) and price it.
8. Decision 4 (model): Add the oxygen sensor option and its mounting position (breathing height) to the model and the wiring diagram.
9. Decision 6 (model): Add the differential pressure switch and its tubing at the fan to the model and wiring; add its fault to the controller logic.
10. Decision 6 (bom): Add the differential pressure switch and tubing and price them.
11. Decision 6 (calcs): HGD-CAL-001 Table 4 (FMEA): move the blocked duct and stuck shutter from dangerous undetected to detected; R5 fault time for the pressure switch.
12. Decision 7 (bom): BOM line 11: specify a valve rated for hydrogen with a stated seat leak rate, or record the brass valve maker's ratings; reprice if needed.
13. Decision 7 (calcs): HGD-CAL-001 Table 4: the leaking valve seat stays a dangerous fault covered by the valve rating and the TRL 4 seat leak proof test; say so.
14. Decision 8 (calcs): Set the bump test pass level once the cup delivery factor is measured (TRL 4).
15. Decision 9 (model): Add the dry-contact relay output and terminal on the controller mounting plate (model, wiring diagram, build plan picture).
16. Decision 9 (bom): Add the relay and terminal for the dry-contact output and price them.
17. Decision 11 (bom): BOM line 5: change to a clear-lid IP65 controller box at the next revision.
18. Decision 10 (pictures): Add a caption to the product renders saying the head and valve are drawn beside the controller; at the next render session, redraw them to the constructable design.

### Points found in the review

Raised when the recommendations were written (2026-10-01) and not yet acted on:

- The calculation note marks placement as met for the head-placement requirement, but the modelled ports are 260 mm from the apparatus centre against a 141 mm plume radius, which does not meet the decided rule of a head directly above each likely leak point.
- Four dangerous undetected faults remain in the fault table (blocked duct, poisoned sensor, blocked port, leaking valve); items 6 and 7 address two of them and should be decided before any gas is connected.
- The value-engineering note quotes USD 226 without the fan and grille; that is a different scope from the USD 265 target.

## Session 2026-10-02: approved follow-ups carried out

Amish approved on 2026-10-02 that every follow-up action from the open-decision sign-off be carried out ("APPROVED CHANGES, COMPLETE THESE"). Nothing was built or tested; the work stays at TRL 3.

### Approved follow-ups carried out

Numbers are those of the follow-up list in the section above. 17 of 18 done.

1. Done. The head hangs from the ceiling on a drop rod (1/2 in floor flange, 89 mm pipe nipple, two locknuts) with its ports 175 mm below the ceiling and 0 mm from the apparatus centre; back-wall screws and holes removed, gland moved 38 mm left of the rod. Constructability checks 182 pass, 0 fail (was 127), with new checks for the drop rod contacts, the port offset, the ports' height, the oxygen cell height, the ceiling fixings and every new part's clearances. STEP and STL re-exported.
2. Done. HGD-DWG-001 Rev P5 (also corrects the leader and dimension positions, which were offset from the parts); new making sketch HGD-DWG-110 (drop rod and ceiling plate); HGD-DWG-101 Rev P2 (head box drilling); concept blueprint HGD-DWG-010 Rev P5.
3. Done. Build plan section 3.4 (drop rod, with joint 8) and step 4 rewritten; overview, step and joint pictures regenerated; the "Head over the leak point" check now passes when the plumb line from midway between the ports lands within 20 mm of the apparatus centre.
4. Done. HGD-CAL-001 E7 computes the port offset (0 mm on the drop rod, inside the 141 mm plume radius; 260 mm at the former wall position); R1 placement now met on the drop rod, and the v0.3 note's error is recorded.
5. Done. BOM line 17, ceiling drop rod, USD 11.
6. Done. Installation notes (build plan section 3.11, BOM line 9 note) say a room used without close supervision needs a fan with its motor outside the air stream; BOM line 21, quantity 0 option, USD 450.
7. Done. BOM line 20, oxygen sensor option (transmitter, cable, 150 ohm input on the trip board), quantity 0, USD 110.
8. Done. Oxygen transmitter in the model on the back wall with its cell at 1,480 mm; wiring diagram and build plan step 15.
9. Done. Pressure switch on the wall left of the fan, its low port tubed to a static tap just inside the grille in the fan inlet, in the model and wiring; controller logic: no airflow for 10 s with the fan running closes the valve and latches (build plan section 3.6.1, precis).
10. Done. BOM line 18, pressure switch and tubing, USD 30.
11. Done. HGD-CAL-001 G6 (inlet tap 5.7 Pa at 150 m3/h, 30.5 Pa at full speed, set point 2.8 Pa) and F6 (airflow fault 0.12 s after 10 s); Table 4 moves the blocked duct and stuck shutter to detected.
12. Done. BOM line 11 re-specified as a stainless valve rated for hydrogen with a stated seat leak rate, USD 95 (was USD 30, brass). No brass valve maker's ratings were recorded: no maker is chosen.
13. Done. HGD-CAL-001 Table 4 says the leaking valve seat stays a dangerous undetected fault, covered by the valve rating and the TRL 4 seat leak proof test.
14. Not done: TRL 4 work (the pass level needs the measured cup delivery factor).
15. Done. Dry-contact relay and 2-way terminal on the controller mounting plate in the model, wiring diagram, sketch HGD-DWG-106 Rev P2 and step 5 picture.
16. Done. BOM line 19, USD 6.
17. Done. BOM line 5 now a clear-lid IP65 box with eight glands, USD 20 (was USD 15).
18. Done. Render captions (RENDER_VIEWS notes in `cad/src/product_model.py`) say the head and valve are drawn beside the controller; the head is redrawn on its drop rod and the valve on its bracket, from model.py's parts. Photoreal renders are not regenerated here (made on Amish's Mac).

### Documents changed

- `docs/04-calcs/01-sizing.md` (HGD-CAL-001 v0.4), `docs/04-calcs/sizing.py`, `docs/04-calcs/results.txt`
- `docs/03-requirements.md` (HGD-REQ-001 v0.7)
- `docs/02-concept.md` (HGD-PRC-001 v0.7)
- `docs/01-problem.md` (HGD-PRB-001 v0.8)
- `docs/05-build-plan.md` (HGD-BLD-001 v0.3), with every picture in `docs/05-build-plan/` and `cad/drawings/HGD-DWG-101` to `110` regenerated
- `docs/decisions/0003-design-for-construction.md` (HGD-DDR-003 v0.3): consequences updated
- `docs/06-design-decisions.md` (HGD-DEC-001 v0.3): value engineering re-priced; items to confirm 8 to 10 (low-range switch, drop rod threads, dry-contact rating)
- `cad/src/model.py`, `cad/src/sheets.py`, `cad/src/concept_media.py`, `cad/src/build_plan_media.py`, `cad/src/product_model.py`; `cad/step/`, `cad/stl/`, `cad/drawings/`, `media/` (hero, blueprint, exploded, cutaway, flow, model.glb)
- `bom/bom.csv` (21 lines), `bom/bom-notes.md`, `README.md` (not controlled documents)
- `docs/pdf/`: every controlled document re-rendered

### Requirement status changes

- R1: placement now met (ports 0 mm from the apparatus centre on the drop rod); v0.3 recorded placement as met with the wall position, which did not meet the rule. Still not verifiable at TRL 3 overall (resolution needs sensor data).
- R5: met on paper with three dangerous undetected faults (was four).
- R13: at risk (4.2 h) becomes **not met on estimate**: 5.0 h against 4 h, after the drop rod, pressure switch, more cable and ceiling clips added 45 min.
- R14: over the value-engineering target by USD 146 (was USD 24).
- R11: 48.7 W peak (49.2 W with the oxygen sensor), still met.

### Cost and mass

Value-engineering target: USD 265. Estimated cost of the constructable design: USD 411 (USD 146 over the target). `budget_usd` is unchanged. Options not in the total: oxygen sensor USD 110; fan with its motor outside the air stream USD 450 in place of the USD 55 fan. The repo carries no mass figure, so there was no mass to update.

### Cross-repo actions

- H2Bench: wire H2Guard's dry-contact output (opens on a trip, a fault or loss of power; 2 A at 30 V DC) into its own supply cut-off and tank solenoid circuit, and record the interface in its documents.

### Points for Amish

- The pressure switch sees only 5.7 Pa at the continuous flow, so it needs a low-range switch set at about 3 Pa (register item 8). If none can be bought at the line 18 price, the alternatives are a digital differential pressure sensor read by the microcontroller, or proving airflow only on boost. Proposed, awaiting Amish if the item fails at purchase.
- The hydrogen-rated valve is now the largest single cost (USD 95). The brass valve route (USD 65 less) needs a maker's statement and the TRL 4 proof test.
- R13 is now 60 min over on a judgment estimate; whether to restate the 4 h target or accept it is for Amish (proposed, awaiting Amish).

### Appearance model deviations (Proposed, awaiting Amish)

- The head and valve stay drawn beside the controller for a compact render, as accepted on 2026-10-02 (decision 10), now with their drop rod and bracket from model.py; the fan, pressure switch, oxygen sensor, grille, sounder, beacon and supply are left out of the renders (decision 13 covers the fan, grille, sounder, beacon and supply; leaving out the pressure switch and oxygen sensor is proposed).
- The controller's internal board is drawn as one board with relays rather than model.py's plate and separate modules, as before.

### Safety

- A leaking valve seat is still not detected in operation; check the valve closes on TEST every session until the TRL 4 seat leak proof test is done.
- No gas is to be connected until the safety stops of the build plan (S3 to S5) are met; the follow-ups for decisions 2, 6 and 7 are now in the design.

## 2026-10-02: photoreal renders redone on the constructable design

Rendered with Blender Cycles on Amish's Mac from the updated appearance model; captioned with `.kit/photo_caption.py`; `media/card.png` and `media/social-preview.png` regenerated with `.kit/cards.py`. Views: hero, exploded, detail. image_qc passes. Appearance deviations are those logged above as proposed, awaiting Amish.

## 2026-10-03: decisions recorded

Amish decided on 2026-10-03: "Cost over target - i accept all the cost variations and overruns". Recorded for this repo: the estimated cost of USD 411 against the USD 265 target (USD 146 over).

- `docs/06-design-decisions.md`: row added to decisions made; value engineering section says the overrun was accepted by Amish on 2026-10-03.

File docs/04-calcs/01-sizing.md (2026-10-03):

---
doc_id: HGD-CAL-001
title: H2Guard sizing calculations
project: H2Guard
doc_type: Calculation note
version: "0.4"
status: Draft
date: '2026-10-02'
author: Amish Chadha
license: CERN-OHL-S-2.0
revisions:
- version: "0.1"
  date: '2026-09-25'
  author: Amish Chadha
  change: First TRL 3 sizing note (sources and inventory, build-up, dilution, plume at the head, response chain, arrestor lag, fan and duct system, power, bump test, alarm level, placement, installation time, cost, trip chain FMEA)
- version: "0.2"
  date: '2026-09-25'
  author: Amish Chadha
  change: Recommendations accepted by Amish (DDR-002); budget $265, R13 scope, timed escalation (F7, F8) and head placement basis (E7) added; status table updated
- version: "0.3"
  date: '2026-10-01'
  author: Amish Chadha
  change: Design for construction (HGD-DDR-003); bump test tube run, installation time and cost re-run; budget treated as a value-engineering target
- version: "0.4"
  date: '2026-10-02'
  author: Amish Chadha
  change: Decisions of 2026-10-02 carried in (HGD-DEC-001); head on a ceiling drop rod over the apparatus (E7, R1 placement), pressure switch airflow proving (G6, F6, Table 4), hydrogen-rated valve, dry-contact output and oxygen sensor option (H1 to H3), tripping bump test, installation time and cost re-run (M1, N1 to N3)
---

# H2Guard sizing calculations

On paper, H2Guard meets ten of its fifteen requirements (six by calculation, four by design), has two at risk, one not met on its estimate and one that cannot be verified at TRL 3, and the cost (R14) is reported against the value-engineering target. Amish accepted the review recommendations on 2026-09-25 (HGD-DDR-002) and decided the remaining open decisions on 2026-10-02 (HGD-DEC-001); this version carries those decisions into the design. **Cost:** Value-engineering target: USD 265. Estimated cost of the constructable design: USD 411 (USD 146 over the target). The hydrogen-rated valve (USD 65 more than the brass valve), the pressure switch, the drop rod, the dry-contact output, the clear-lid box and more cable account for the increase from USD 289. **R13 (installation) is not met on the estimate**: with the wall openings builder's work outside the target, the estimate is 5.0 h against 4 h, after the drop rod, the pressure switch and their cables were added. R4 (response time) is at risk because the catalytic sensor's t90 is still an assumed 30 s, and R7 (ventilation) is at risk because the fan curve is assumed. R1's resolution cannot be checked without sensor data. The calculations changed three parts of the TRL 2 concept: the 300 m3/h axial fan cannot deliver the 300 m3/h boost against the duct and grille losses (237 m3/h), so it is re-specified as a 450 m3/h mixed-flow fan; the 5 mm flame arrestor disc with the sensor 15 mm behind it would add about 21 s of diffusion lag, so the disc is 2 mm thick with the sensor about 2 mm behind it (1.5 s); and a bump test cup, tube and port are added so that R12 can be met. The design leak trips the system at once only if the detector head sits on the plume axis; off the axis the head sees about 15 % LFL and warns. The head now hangs from the ceiling on a drop rod with its ports directly over the apparatus, so the port offset is zero (Section E). The accepted timed escalation now closes the supply when a warning is held for 5 min, at about 5.6 min for the off-axis design leak with 28 L released (Section F). Every number in this note is printed by `docs/04-calcs/sizing.py`; the tag in brackets, for example [E2], is the line of that script's output that carries it.

> **Safety:** These are first-principles estimates for a paper proof of concept. They do not show that a room is safe, and H2Guard is a research and teaching prototype, not a certified gas detection system. Hydrogen is flammable in air from about 4 % to 74 % by volume. See HGD-PRC-001, Safety.

## Scope and method

The note checks every requirement in HGD-REQ-001 v0.7 against the design in HGD-PRC-001 v0.7 and the parametric model `cad/src/model.py`. The script imports the model's `PARAMS` and derived dimensions, so the room, mounting heights, sensor cavity, bump test cup and tube are those in the STEP files and in drawing HGD-DWG-001. It also reads `bom/bom.csv` and `budget_usd` in `project.yaml`. Run it from the repo root with `python docs/04-calcs/sizing.py`; it also writes `docs/04-calcs/results.txt`.

The design case is the 30 m3 reference room (4 x 3 x 2.5 m) with a 5 L/min hydrogen leak from fittings on the bench apparatus, 1,150 mm above the floor, with the detector head directly above it.

## Assumptions

*Table 1. Main assumptions.*

| Area | Assumption | Basis |
| --- | --- | --- |
| Hydrogen | LFL 4.0 % vol; 20 °C, 1 atm; molar volume 24.05 L/mol; density 0.0838 kg/m3 (air 1.204) | US DOE fact sheet cited in HGD-PRB-001; ideal gas |
| Leak | 5 L/min design leak downstream of a flow restrictor; point source at the top of the apparatus | HGD-REQ-001 |
| Plume | Morton, Taylor and Turner point-source plume, top-hat entrainment coefficient 0.10 (0.08 to 0.12 checked); axis value twice the top-hat mean; leak momentum and non-Boussinesq effects near the source ignored | Textbook plume theory; the factor of two is an assumption |
| Ventilation | Exhaust at high level, make-up air at low level on the far side; general ventilation of the room taken as zero | HGD-REQ-001 |
| Airflow proving | Static tap in the fan inlet, just inside the grille: depression is the grille loss plus one velocity head (K 1.7 on the 150 mm duct velocity); switch set at half the continuous-flow value | First principles; to confirm at TRL 4 |
| Duct losses | Loss coefficients on the 150 mm duct velocity: inside grille 0.7, backdraft shutter 1.2, weather hood with exit 1.5, sleeve friction factor 0.03; make-up grille K 2.0 on 50 % free area | Handbook ranges; to confirm with the chosen parts |
| Fan curves | Quadratic, p = p0 (1 - (Q/Qmax)^2). TRL 2 axial fan: Qmax 300 m3/h, p0 100 Pa. TRL 3 mixed-flow fan: Qmax 450 m3/h, p0 200 Pa, 35 W input at full speed; power scales with speed cubed | Typical 150 mm fans; no datasheet chosen yet |
| Sensor | Catalytic sensor t90 30 s (target, not confirmed); power 0.5 W; MOS sensor 0.28 W | TRL 2 figures; the Figaro page fetched on 2026-09-25 says only "fast response" |
| Arrestor | Sintered stainless disc, porosity 0.40, tortuosity 3; hydrogen diffusivity in air 0.61 cm2/s at 0 °C, scaled by T^1.75 | Handbook values |
| Trip chain | Comparator 0.05 s, relay drop-out 0.02 s, valve closing 0.10 s with a Zener clamp on the coil; watchdog 1.0 s | Typical small parts; to confirm |
| Other loads | Controller and display 0.5 W; valve coil 8 W; sounder and beacon 3 W; dry-contact relay coil 0.4 W while healthy; oxygen transmitter option 0.5 W | TRL 2 figures; typical small relay and 4 to 20 mA loop |
| Bump test | Span gas 1 % vol hydrogen at 1.0 L/min; cup flushed by five volumes; 34 L disposable cylinder | Common practice; cup delivery factor not known |
| Installation | Task times in Section M are estimates for one competent person with hand tools and a core drill | Judgment; to confirm in use |

## A. Set points

- Warning at 10 % LFL is 0.40 % vol; trip at 25 % LFL is 1.00 % vol [A1]. The reference room is 30.0 m3 with a 12.0 m2 ceiling [A2].

## B. Sources and inventory (R8, R9)

- **Electrolyzer.** A 100 W PEM stack at 1.9 V per cell makes 2.73 x 10^-4 mol/s, 0.39 L/min. The 5 L/min design leak is 13 times this [B1].
- **Inventory limit.** One percent of the room volume is 300 L at 1 atm, 25.1 g of hydrogen [B2]. H2Bench's 2 L tank at 300 kPa gauge holds 7.9 L, 2.6 % of the limit; a 10 L cylinder at 200 bar holds 1.75 m3, 5.8 times the limit [B3].
- **Flow restrictor.** A choked orifice of 0.13 mm at 10 bar gauge, or 0.21 mm at 3 bar gauge, limits a full-bore failure downstream to the design leak [B4]. This sizes the restrictor in the gas system; it is not H2Guard hardware.

## C. Build-up without ventilation

*Table 2. Time to reach the set points with a 5 L/min leak and no ventilation [C1, C2].*

| Level | Ceiling layer 0.3 m (3.6 m3) | Time | Whole room mixed | Time |
| --- | --- | --- | --- | --- |
| 10 % LFL | 14 L | 2.9 min | 120 L | 24 min |
| 25 % LFL | 36 L | 7.2 min | 300 L | 60 min |
| 100 % LFL | 144 L | 28.8 min | 1,200 L | 240 min |

The TRL 2 figures stand.

## D. Dilution with ventilation (R8)

- **Well mixed.** At 150 m3/h the steady concentration for the design leak is 0.200 % vol (5.0 % LFL); at 300 m3/h it is 0.100 % vol (2.5 % LFL). The electrolyzer case gives 0.0157 % vol [D1]. The room time constant at 5 air changes per hour is 12 min [D2].
- **Stratified.** With exhaust at high level, all the hydrogen leaves through the fan at steady state, so the upper layer settles at the exhaust value, 5.0 % LFL [D3]. The plume would carry the full exhaust flow only 2.28 m above the source, and the ceiling is 1.35 m above it, so no clean interface forms: the room above source height is at about the exhaust value [D4]. The TRL 2 worry that the ceiling layer could be five times richer than the room average does not hold at steady state; it does hold near the plume (Section E) and in the first minutes of a leak.

## E. Plume at the detector head (R2, R3)

- **Plume.** The design leak has a buoyancy flux of 7.61 x 10^-4 m4/s3; the sensor ports are 1.175 m above the source [E1]. At the head the plume carries 13.8 L/s of mixture at a mean of 0.60 % vol (15 % LFL), and about 1.21 % vol (30 % LFL) on its axis [E2]. It rises at 0.22 m/s and takes 4.0 s to reach the head [E3].
- **What the head sees.** A head on the plume axis reads above the trip; a head beside the axis reads about the mean and warns but does not trip [E4]. Leaks of 3.8 L/min or more reach 25 % LFL on the axis; leaks of 2.7 L/min or more bring the plume mean to 10 % LFL [E5]. An entrainment coefficient between 0.08 and 0.12 moves the axis value to between 24 and 41 % LFL [E6]. The plume's top-hat radius at the ports is about 141 mm. On the ceiling drop rod the centre of the two ports is 0 mm from the apparatus centre, inside the plume; at the former wall position it was 260 mm away, outside it [E7].
- **Consequence.** For the design leak with the fan running, the room stays at about 5 % LFL (R8 met), but whether the supply closes depends on the head being on the plume axis. A smaller leak, or a leak from a fitting away from the head, is warned but not stopped by the set points alone. Amish accepted two remedies on 2026-09-25 (HGD-DDR-002): a timed escalation that closes the valve when a warning is held for 5 min (Section F, [F7]), and a placement rule that keeps the head directly above each likely leak point, with a second head where leak points are far apart. On 2026-10-02 Amish decided that the head hangs from the ceiling on a drop rod directly over the apparatus (HGD-DEC-001, decision 2); the model now places it there, with its ports 175 mm below the ceiling [E7, L1]. The horizontal offset limit for other rooms is to be set at TRL 4 from a measured plume width; the 141 mm radius above is the paper basis.
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

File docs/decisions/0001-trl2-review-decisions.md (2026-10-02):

---
doc_id: HGD-DDR-001
title: H2Guard TRL 2 review decisions
project: H2Guard
doc_type: Design decision record
version: "0.3"
status: Draft
date: '2026-10-02'
author: Amish Chadha
license: CERN-OHL-S-2.0
revisions:
- version: "0.1"
  date: '2026-09-25'
  author: Amish Chadha
  change: Record the TRL 2 review items adopted for TRL 3 work under Amish's 2026-09-25 instruction, and the items that remain open
- version: "0.2"
  date: '2026-09-25'
  author: Amish Chadha
  change: Recommendations accepted by Amish (DDR-002); D1 to D9 and O1 decided, O2 to O5 still open
- version: "0.3"
  date: '2026-10-02'
  author: Amish Chadha
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

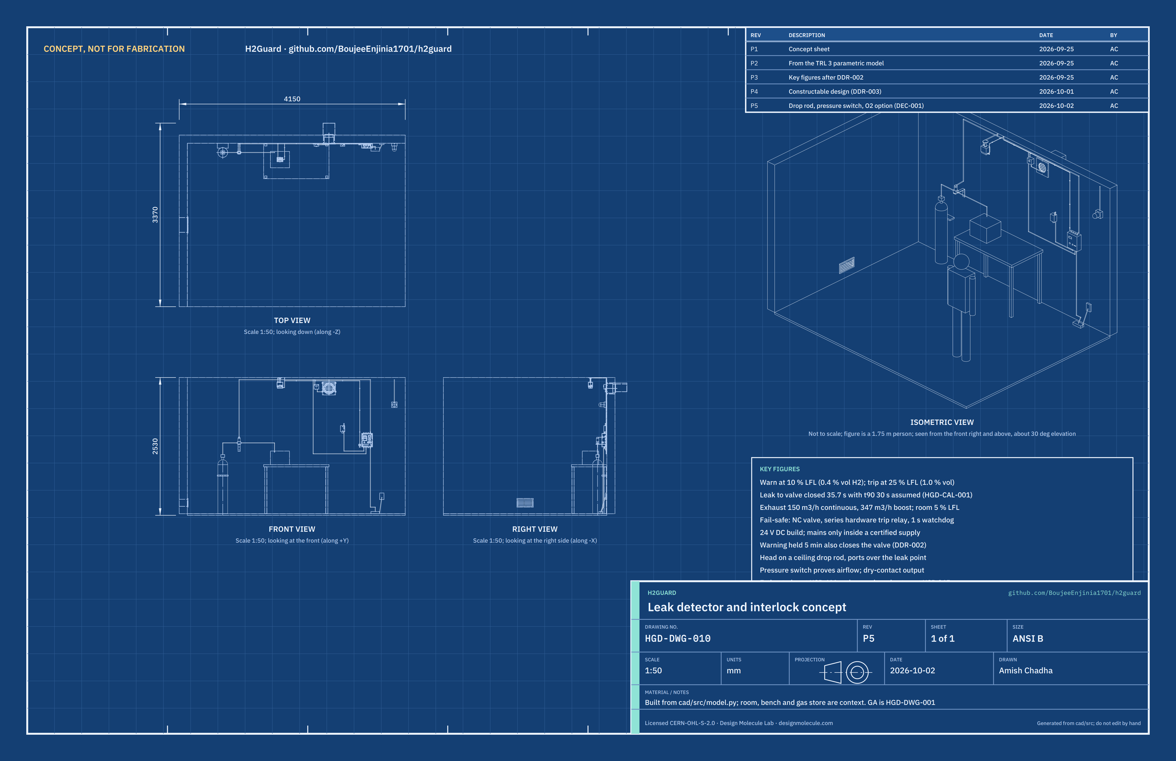
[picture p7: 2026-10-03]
media/concept-blueprint.png

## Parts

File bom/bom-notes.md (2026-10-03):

# BOM notes

- Line numbers 1 to 12, 15, 17, 18 and 20 match the callouts in `media/exploded.png`, the numbered parts in `cad/src/concept_media.py` and the part keys in `cad/src/model.py` (`BOM_ORDER`). Lines 13, 14, 19 (inside the controller) and 21 (not modelled) have no callout.
- All prices are indicative single-unit estimates in USD (September and October 2026) and have not been checked against quotes. Value-engineering target: USD 265 (`budget_usd`, a hypothetical control target, not a limit). Estimated cost of the constructable design: USD 411 (USD 146 over the target); see HGD-CAL-001, N1. Without the fan and make-up grille the kit is USD 348.
- Line 16 (made brackets and plates) and the re-specified lines 1, 2, 4, 5, 6, 7, 9, 11, 14 and 15 come from the design for construction (HGD-DDR-003, 2026-10-01); the build plan HGD-BLD-001 shows how each part is made and fitted.
- Changes at TRL 3: the fan (line 9) is re-specified as a 450 m3/h mixed-flow fan (+$15) because a 300 m3/h axial fan cannot give the 300 m3/h boost against the duct losses; the arrestor discs (line 4) are 2 mm instead of 5 mm and the drip skirt becomes the bump test cup (+$1); the bump test port and tube (line 15, $9) are new; the controller board (line 6) now calls for 4 MB of flash and a series trip relay at no price change.
- Supplier types are given; no line is tied to a quote or a purchase. Purchasing is TRL 4 work and is not started.
- Not included: the hydrogen source, regulator, supply tubing, any flow restrictor and the gas fitting work. These belong to the gas system (for example H2Bench) and must be installed by a competent person. HGD-CAL-001 (B4) sizes the restrictor orifice.
- Decided on 2026-10-02 (HGD-DEC-001) and added on the same day: line 17, the ceiling drop rod for the head (USD 11); line 18, the differential pressure switch and its tube (USD 30); line 19, the dry-contact relay and terminal (USD 6); line 5 re-specified with a clear lid and eight glands (USD 15 to 20); line 11 re-specified as a stainless valve rated for hydrogen with a stated seat leak rate (USD 30 to 95); line 13 with 7 m more cable (USD 15 to 20). Two options are priced with quantity 0 and are not in the total: line 20, the oxygen sensor for rooms where inert gas cylinders are kept (USD 110), and line 21, a fan with its motor outside the air stream for rooms used without close supervision (USD 450, in place of line 9). Each new price is an indicative catalogue range, stated in the line's notes; none is quoted.
- Not included: certified span gas for bump tests (1 % hydrogen in air), its cylinder regulator and the wall openings for the fan and grille.
- A certified hydrogen sensing element (for example a NevadaNano MPS sensor, listed at about $249) would replace lines 2 and 3 and raise the total to about $465; see the precis (D1 upgrade path).

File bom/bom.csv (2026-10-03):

item | qty | spec | supplier | unit_cost_usd | make_buy | notes
1 Detector head enclosure | 1 | ABS or polycarbonate box 110 x 80 x 90 mm with its lid on the 110 x 90 room-side face; drilled: two 22 mm sensor ports in the floor, a 21.7 mm hole at the centre of the top for the drop rod (line 17), a 16.2 mm gland hole 38 mm left of it with an M16 cable gland, and four 3.4 mm standoff screw holes in the floor; see HGD-DWG-101 | Electronics distributor | 8.00 | buy | Indicative price; hangs from the ceiling on the drop rod (line 17) with its sensor ports 175 mm below the ceiling directly over the apparatus (HGD-DEC-001, decision 2); ports reduced from 26 to 22 mm so the 25 mm arrestor discs rest on a ledge (HGD-DDR-003)
2 Catalytic hydrogen sensor | 1 | Catalytic (pellistor) combustible gas sensor with hydrogen response, 0 to 100 % LFL, for example Figaro TGS6812-D00, soldered under a 100 x 70 mm prototype carrier board with the bridge supply and the MOS heater regulator; board on four M3 x 22 mm standoffs (line 14); see HGD-DWG-102 | Electronics distributor (Figaro) | 35.00 | buy | Indicative price; primary trip sensor; t90 and power still to be confirmed from the datasheet (HGD-CAL-001)
3 MOS hydrogen sensor | 1 | Metal oxide hydrogen sensor, about 30 to 3000 ppm, for example Figaro TGS2616-C00, 5 V heater about 280 mW | Electronics distributor (Figaro) | 15.00 | buy | Indicative price; early warning and trend only; never used alone to trip
4 Flame arrestor discs and bump test cup | 1 | Two sintered stainless steel discs 25 mm diameter x 2 mm, pore size 50 um or less, bonded on the floor of the head over the 22 mm ports with two-part epoxy (no silicone), sensor can 2.2 mm above each disc; drip skirt 96 x 66 x 22 mm printed in PETG as the bump test cup, with a 2 mm top plate, two 22 mm openings over the ports and a side boss tapped M5 for the push-in fitting (line 15); see HGD-DWG-103 | Industrial filter supplier; 3D print for the cup | 7.00 | buy | Indicative price; disc thinned from 5 mm to 2 mm (HGD-CAL-001 F1 and F2); not a certified flameproof assembly; cup top plate opened over the ports and fixed by the standoff screws (HGD-DDR-003)
5 Controller enclosure | 1 | IP65 polycarbonate wall box 200 x 250 x 90 mm with a clear polycarbonate lid, four moulded bosses inside the back and corner fixing holes outside the seal; eight M16 cable glands (four in the top; four in the bottom for the oxygen sensor, pressure switch, dry-contact output and supply lead); lid drilled for the front panel parts; top at least 1 m below the ceiling; see HGD-DWG-104 and HGD-DWG-105 | Electronics distributor | 20.00 | buy | Indicative price; clear lid so the status lights and relays can be seen without opening the box (HGD-DEC-001, decision 11); about USD 5 more than a grey-lid box of the same size, an estimate from distributor catalogue ranges, not a quote; three more glands than before
6 Controller board | 1 | RP2040-class microcontroller module with 4 MB flash or more; trip board on prototype board with the sensor bridge input, a hardware window comparator with a hardware latch, and the bridge and heater supplies; relay module with the series trip relay and the fan relay; valve and alarm driver module; terminal strip; all on 6 mm nylon standoffs on the mounting plate (line 16); fan PWM and tachometer; pressure switch input that closes the valve when airflow is not proved within 10 s of the fan running; 1 s watchdog | Electronics distributor; prototype board | 25.00 | make | Indicative parts price; block-level wiring at TRL 3 (no circuit board laid out); firmware limited to a labeled sketch
7 Front panel | 1 | Small OLED display module behind a window in the controller lid, key-switch reset (19 mm hole), test button (16 mm hole), three 5 mm status LEDs in bezels | Electronics distributor | 12.00 | buy | Indicative price
8 24 V DC power supply | 1 | Certified plug-in or desktop supply, 24 V, 2.5 A (60 W), with DC plug | Electronics distributor | 15.00 | buy | Indicative price; keeps mains out of the self-built parts; peak load about 48 W (HGD-CAL-001 H2)
9 Exhaust fan | 1 | 150 mm mixed-flow EC duct fan, 24 V, about 450 m3/h free air and 200 Pa shut-off, PWM speed input and tachometer output, body about 170 mm diameter with a flat inlet face carrying four fixing holes; inside grille 240 mm square, 200 mm wall sleeve 150 mm long, backdraft shutter on the outlet spigot and weather hood with fixing tabs | HVAC supplier | 55.00 | buy | Indicative price; re-specified from a 300 m3/h axial fan that cannot reach the 300 m3/h boost against the duct losses (HGD-CAL-001 G3); sleeve enlarged from 150 to 200 mm so the fan body fits inside the wall, air path still 150 mm through the fan (HGD-DDR-003); not rated for hazardous areas; motor in the air stream, accepted for the supervised teaching prototype only (HGD-DEC-001, decision 3); line 21 is the alternative for rooms used without close supervision
10 Make-up air grille | 1 | Low-level wall grille 300 x 160 mm with insect mesh, about 50 % free area | Hardware store | 8.00 | buy | Indicative price; on the far side of the room from the fan
11 Normally closed solenoid valve, hydrogen rated | 1 | 2/2-way, normally closed, direct acting, 1/4 in, stainless steel body with FKM or PTFE seals and two tapped mounting holes underneath, 24 V DC coil about 8 W, 0 to 10 bar; the maker states hydrogen compatibility and a seat leak rate (for example ISO 5208 rate A or EN 161 class A); Zener clamp for fast closing; on the valve bracket (line 16) | Pneumatic or valve supplier | 95.00 | buy | Indicative price from catalogue ranges for small stainless direct-acting valves (about USD 80 to 150), not a quote; re-specified from the USD 30 brass valve (HGD-DEC-001, decision 7); the brass valve is accepted only if its maker states hydrogen compatibility and a seat leak rating and it passes a seat leak proof test at TRL 4; certified gas safety shut-off valves cost several times more
12 Sounder and beacon | 1 | 24 V DC combined sounder (about 90 dB at 1 m) and red flashing beacon | Electronics distributor | 12.00 | buy | Indicative price; top 450 mm below the ceiling by the door
13 Cable and conduit | 1 | Four-core and two-core cable, about 22 m total, cable glands, surface conduit | Electronics distributor | 20.00 | buy | Indicative price; about 7 m more for the pressure switch and dry-contact output cables (about USD 0.70 a metre); no exploded-view callout
14 Hardware and consumables | 1 | Four M3 x 22 mm female standoffs and M3 screws (head); 6 mm nylon standoffs and M3 screws (modules); M4 screws for the mounting plate, fan and brackets; M5 screws for the valve; M6 and M4 screws with wall plugs; two-part epoxy; ferrules, heat-shrink, labels | Hardware store | 12.00 | buy | Indicative price; no exploded-view callout
15 Bump test port and tube | 1 | Bulkhead push-fit test port for 4 mm tube with M12 thread and dust cap, on the test port bracket (line 16) beside the controller; about 3.5 m of 4 mm OD x 2.5 mm bore PTFE or PA tube to the cup; M5 straight push-in fitting at the cup; six saddle clips on the wall and two on the ceiling | Pneumatic fittings supplier | 11.00 | buy | Indicative price; new at TRL 3 to meet R12; the run now crosses the ceiling to the head on its drop rod (3.1 m); span gas and its regulator are not included
16 Made brackets and plates | 1 | Fan plate 240 x 240 x 3 mm aluminium sheet; controller mounting plate 176 x 220 x 2 mm aluminium sheet; valve bracket bent from 40 x 5 mm aluminium flat bar about 330 mm; test port bracket 40 mm of 30 x 30 x 3 mm aluminium angle; see HGD-DWG-106 to 109 | Metal stockholder | 14.00 | make | Indicative material price; new for construction (HGD-DDR-003)
17 Ceiling drop rod | 1 | 1/2 in malleable iron floor flange about 80 mm across used as the ceiling plate, with three 5.5 mm holes on a 60 mm circle; 1/2 in steel pipe nipple 89 mm long (21.3 mm OD); two 1/2 in conduit locknuts, one either side of the head top; three M5 x 40 screws with ceiling plugs; see HGD-DWG-110 | Hardware store; plumbing supplier | 11.00 | buy | Indicative price: flange about USD 6, nipple USD 3, locknuts USD 1, screws and plugs USD 1, from hardware store ranges, not quoted; new (HGD-DEC-001, decision 2); holds the head with its ports 175 mm below the ceiling directly over the apparatus
18 Differential pressure switch and tubing | 1 | Adjustable differential pressure switch for air, low range (set point adjustable down to about 3 Pa), changeover contact rated 24 V DC, two hose barbs for 6 mm tube, about 85 x 85 x 55 mm with two wall screw holes; about 0.5 m of 6 mm OD x 4 mm bore PVC or silicone tube from the low port to a static tap in the fan inlet, just inside the grille; the high port is open to the room | HVAC controls supplier | 30.00 | buy | Indicative price from catalogue ranges for HVAC air pressure switches (about USD 20 to 45), not a quote; new (HGD-DEC-001, decision 6); proves airflow: no flow (fan stopped, duct blocked or shutter stuck) closes the valve within 10 s (HGD-CAL-001 G6); the low set point is to be confirmed when the switch is bought
19 Dry-contact output relay and terminal | 1 | Relay module with a 24 V coil and one changeover contact rated 2 A at 30 V DC, energized while H2Guard is healthy so the contact opens on a trip or loss of power; 2-way 5.08 mm screw terminal; on the mounting plate (line 16) on two 6 mm nylon standoffs | Electronics distributor | 6.00 | buy | Indicative price; new (HGD-DEC-001, decision 9); a volt-free output so H2Bench can cut its own supply; cable out through a bottom gland
20 Oxygen sensor option | 0 | Electrochemical oxygen transmitter 0 to 25 % vol, 24 V DC, 4 to 20 mA output, in an IP65 box about 80 x 110 x 55 mm with the cell facing down, mounted with the cell at breathing height (about 1.5 m); 5 m of two-core 0.5 mm² cable; 150 ohm precision resistor and terminal on the trip board for the microcontroller's analogue input; warning at 19.5 % vol and trip at 18 % vol oxygen | Gas detection or instrument supplier | 110.00 | buy | Option: quantity 0 in the base kit; fit one whenever inert gas cylinders share the room (HGD-DEC-001, decision 4); indicative price from catalogue ranges for oxygen transmitters (about USD 90 to 250), not a quote; not in the estimated cost of the constructable design
21 Exhaust fan with its motor outside the air stream (alternative to line 9) | 0 | 150 mm bifurcated or externally driven duct fan with its motor outside the air stream, about 450 m3/h in free air and 200 Pa at shut-off, with a speed input or a two-speed switch and a run signal; if mains powered, wired by an electrician through a certified contactor driven by the controller's fan relay | HVAC supplier | 450.00 | buy | Option: quantity 0 in the base kit; replaces line 9 in any room used without close supervision (HGD-DEC-001, decision 3); indicative price from catalogue ranges for small bifurcated fans (about USD 350 to 800), not a quote; not in the estimated cost of the constructable design

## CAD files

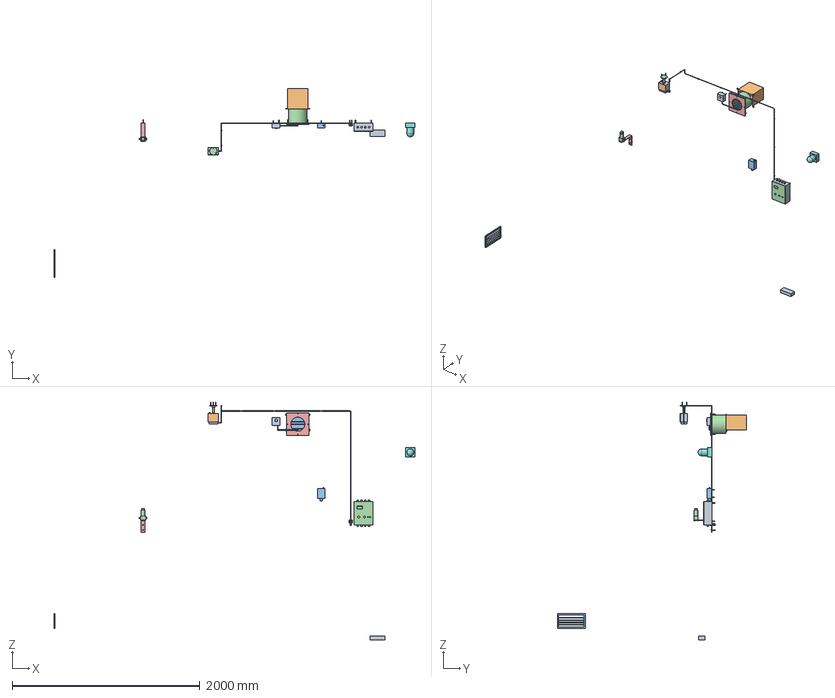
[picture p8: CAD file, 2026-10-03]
cad/step/h2guard-assembly.step
3850.0 x 2020.0 x 2535.0 mm

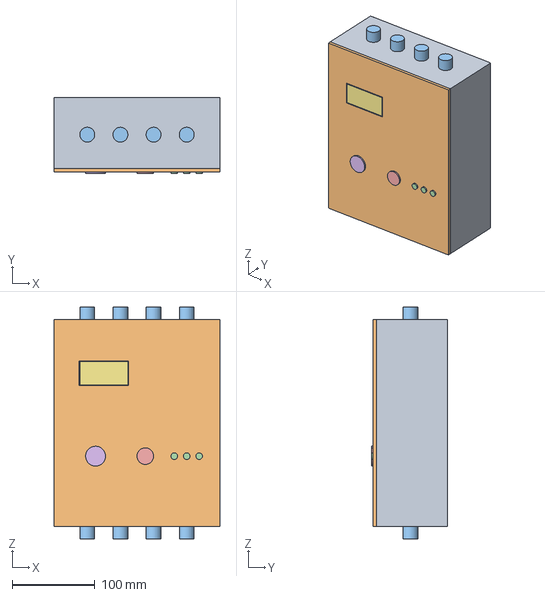
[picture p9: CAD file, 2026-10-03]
cad/step/controller.step
200.0 x 92.0 x 280.0 mm

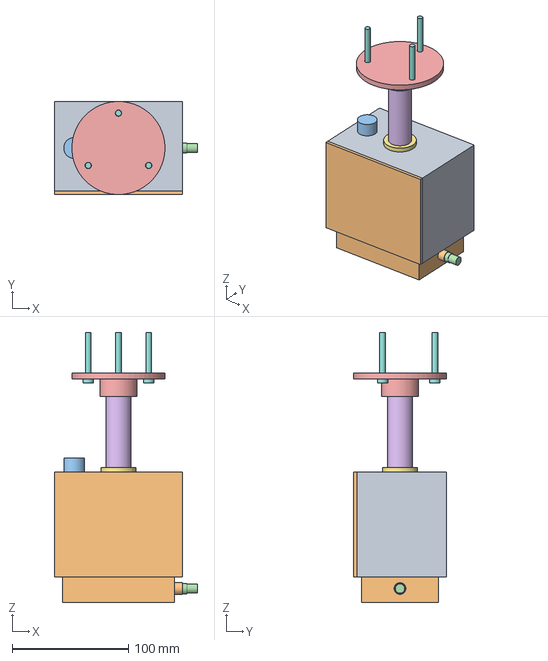
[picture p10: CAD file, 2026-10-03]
cad/step/detector-head.step
123.0 x 80.0 x 232.0 mm

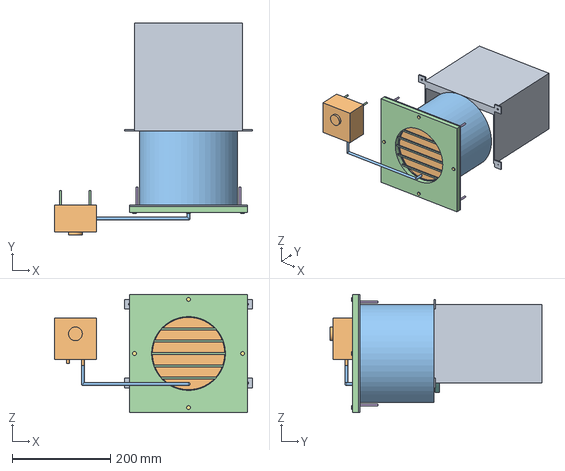
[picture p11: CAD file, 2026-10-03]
cad/step/exhaust-fan.step
402.5 x 431.0 x 240.0 mm

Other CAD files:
cad/stl/controller.stl
cad/stl/detector-head.stl
cad/stl/exhaust-fan.stl
cad/stl/h2guard-assembly.stl

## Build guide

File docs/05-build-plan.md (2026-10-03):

---
doc_id: HGD-BLD-001
title: H2Guard prototype build plan
project: H2Guard
doc_type: Build plan
version: "0.3"
status: Draft
date: '2026-10-02'
author: Amish Chadha
license: CERN-OHL-S-2.0
revisions:
  - version: "0.1"
    date: '2026-10-01'
    author: Amish Chadha
    change: First build plan, with pictures by component and step; design made constructable (HGD-DDR-003)
  - version: "0.2"
    date: '2026-10-02'
    author: Amish Chadha
    change: "Safety stop S5: head placement, airflow proving, valve, oxygen sensor and set point conditions decided on 2026-10-02 (HGD-DEC-001)"
  - version: "0.3"
    date: '2026-10-02'
    author: Amish Chadha
    change: "Decisions of 2026-10-02 carried into the plan: head on a ceiling drop rod (new section 3.4, step 4 rewritten), pressure switch (step 11), dry-contact relay, clear-lid box with eight glands, hydrogen-rated valve, oxygen sensor option (step 15); pictures regenerated"
---

# H2Guard prototype build plan

**Plan, not yet built.** How to build the first proof-of-concept prototype, component by component. Building and testing to it is TRL 4 work. Decisions still to be made are kept in the design decisions register ([docs/06-design-decisions.md](06-design-decisions.md)), not here.

## 1. What you are building

Figure 1. Every component, pulled apart and numbered in build order

*Figure 1. Every component pulled apart and numbered in build order. The tube (24) is drawn short; it is about 3.1 m long.*

The prototype is one H2Guard installed in a teaching room of about 30 m³ (4 x 3 x 2.5 m): a small detector head hanging from the ceiling on a short drop rod directly over the bench apparatus, a controller box with a clear lid at chest height, an exhaust fan high in the back wall with a pressure switch beside it that proves the air is moving, a make-up air grille low on the far side wall, a normally closed solenoid valve rated for hydrogen on the supply, a sounder and beacon by the door, a plug-in 24 V supply, and a thin tube that carries test gas from a port beside the controller up to the head. Where inert gas cylinders share the room, an oxygen sensor is added at breathing height. A relay in the controller gives a volt-free contact that opens on a trip or loss of power, so a host bench can cut its own supply. Figure 1 shows the 25 components in the order you make or fit them. Nine are made or drilled in a small workshop: the head box, the printed bump test cup, the sensor board, the controller box and its lid, the controller mounting plate, the test port bracket, the fan plate and the valve bracket. Everything else is bought and fitted. The work is drilling plastic boxes, cutting and drilling aluminium sheet, angle and flat bar, bending one bar, one 3D print, soldering two sensors to a prototype board and wiring bought modules with screw terminals. The gas connection to the valve is made by a competent gas fitter, and the two wall openings for the fan and the make-up air grille are builder's work. The parts cost about USD 411 from the bill of materials, without the oxygen sensor option.

> **Safety:** Hydrogen is flammable in air from about 4 % to 74 % by volume and ignites very easily. No hydrogen is used while building; the first gas, a certified 1 % test mixture, comes in only at the safety stops of section 6. H2Guard is a research and teaching prototype, not a certified gas detection system, and must not be the only safeguard in a room where certified detection is required. The 24 V supply is a bought, certified plug-in unit: no mains wiring is part of this build.

## 2. What changed to make it buildable

The concept showed what H2Guard does and where each part goes in the room; some of its parts could not be made, fitted or held as drawn. Each change below keeps what the system does. The construction changes are recorded in decision record HGD-DDR-003, accepted by Amish on 2026-10-02; the last five rows come from the decisions Amish made on the same day, recorded in the design decisions register.

*Table 1. Changes from the concept.*

| Component | The concept had | The buildable design has | Why |
| --- | --- | --- | --- |
| Bump test cup | A solid top that covered both sensor ports | Two 22 mm openings over the ports (Figure 3) | Gas can reach the sensors |
| Arrestor discs | 25 mm discs in 26 mm ports, with nothing to hold them | 22 mm ports; each disc rests on the ledge and is bonded round its edge with epoxy (Figure 3) | The disc cannot fall out and gas cannot pass round it |
| Head fixing | A wall plate that cut into the box, and no screws | The box hangs from the ceiling on a short drop rod: a floor flange on the ceiling, a pipe nipple and two locknuts that clamp the top of the box (Figure 9) | The ports sit directly over the leak point, inside the rising plume |
| Sensor board and cup | No fixing | Four 22 mm standoffs: screws from below hold the cup, screws from above hold the board (Figure 5) | One set of parts holds both and sets the sensor height |
| Test gas nozzle | A solid stub | A push-in fitting for 4 mm tube in a boss on the cup (Figure 6) | A standard fitting the tube pushes into |
| Controller inside | A board floating in the box | An aluminium mounting plate on the box's four bosses, modules on standoffs (Figure 12) | Bought modules, nothing floating |
| Front panel | A panel floating in front of the box | The box's own lid, cut for the display, key, button and lights (Figure 14) | The lid seals the box with the panel parts in it |
| Cable entries | None | Five cable glands, four on top and one underneath (Figure 10) | Keeps the box sealed |
| Test port | A block overlapping the port | A short aluminium angle on the wall with the port pointing down through it (Figure 16) | Test gas connects from below at chest height |
| Exhaust fan | A 146 mm motor floating in a 150 mm sleeve | The 170 mm fan body in a 200 mm sleeve, held by a fan plate on the inside wall (Figure 18) | The air path is still 150 mm, so the fan's delivery is unchanged |
| Solenoid valve | Hanging on the gas pipe, which passed through it | On a bent flat-bar bracket from the wall (Figure 21) | The gas joints carry no weight |
| Airflow proving | Fan rotation only | A pressure switch beside the fan, its tube ending in the fan inlet (Figure 19) | A blocked duct or stuck shutter now closes the valve |
| Valve body | Brass, ratings unknown | Stainless steel, rated by its maker for hydrogen with a stated seat leak rate | A leaking seat is the remaining undetected fault |
| Controller box | Grey lid, five glands | Clear lid, eight glands (four on top, four underneath) | Lights and relays seen without opening; room for the new cables |
| Interlock output | None | A dry-contact relay on the mounting plate | A host bench can cut its own supply |
| Oxygen | Not monitored | An oxygen sensor option at breathing height (step 15) | The catalytic sensor reads low in an oxygen-poor room |

## 3. Making the components

Make and check each component before the assembly step that needs it. Sizes are in millimetres. "Left" and "right" are as seen standing in the room facing the wall the part is on. Workshop tolerance is 0.5 mm unless a step says otherwise; drawings do not carry tolerances before TRL 4.

### 3.1 Detector head box, drilled

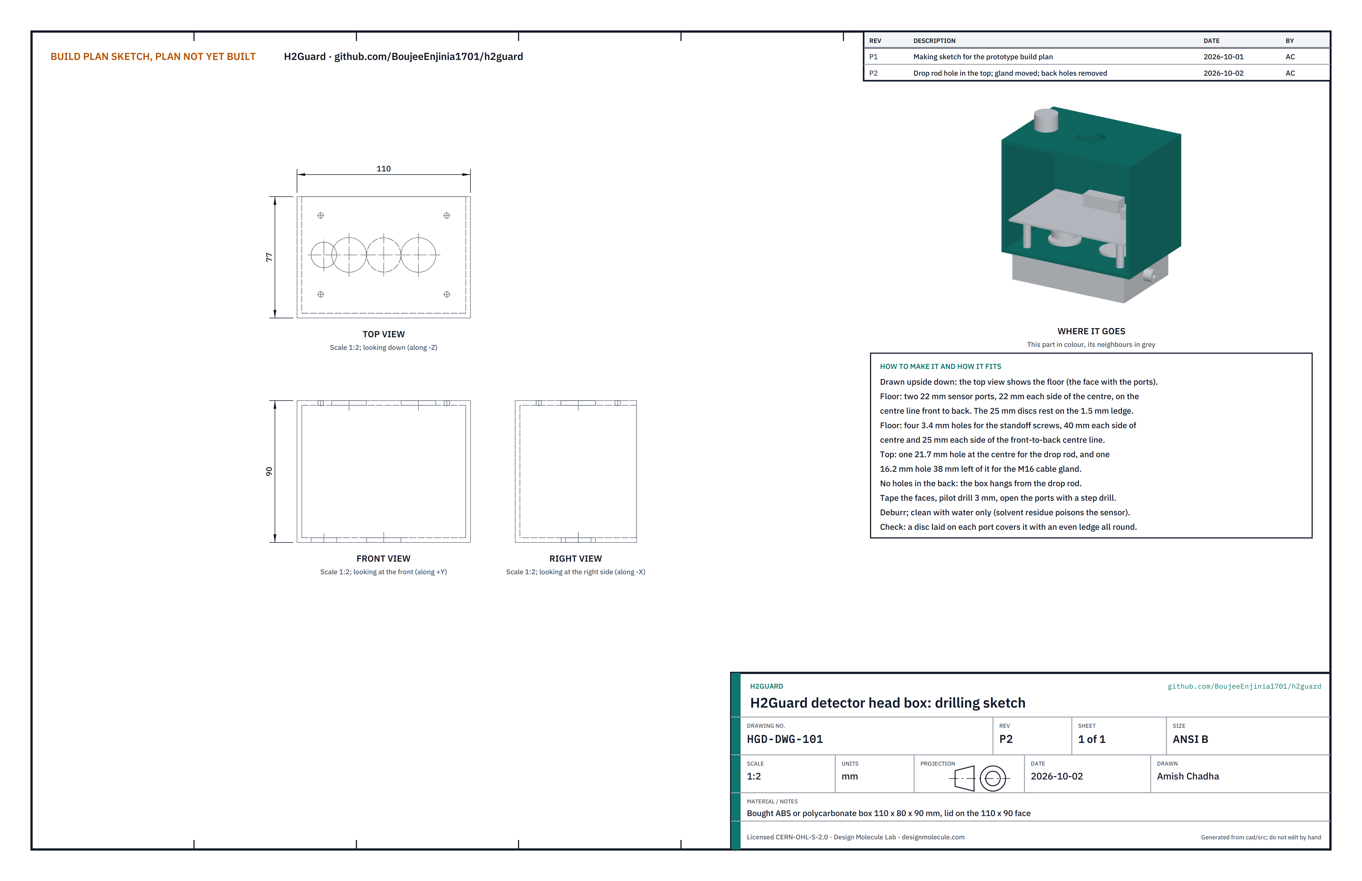
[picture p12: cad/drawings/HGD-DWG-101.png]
Figure 2. Drilling sketch of the detector head box


*Figure 2. Detector head box drilling sketch (HGD-DWG-101), drawn upside down so the top view shows the floor.*

**What it is and what it is made from.** The small box at the ceiling that carries both sensors. A bought ABS or polycarbonate box 110 wide, 80 deep and 90 tall, with its lid on one 110 x 90 face; the lid faces into the room.

**How to make it.**

1. Cover the floor and top with masking tape and mark the centre lines.
2. Floor: two sensor ports, 22 mm diameter, 22 mm each side of the centre on the centre line front to back. Pilot drill 3 mm at low speed with a block of wood behind, then open with a step drill and light pressure.
3. Floor: four 3.4 mm holes for the standoff screws, 40 mm each side of the centre and 25 mm each side of the front-to-back centre line (80 x 50 mm apart).
4. Top: one 21.7 mm hole at the centre for the drop rod, and one 16.2 mm hole for the cable gland, 38 mm left of the centre on the same line. No holes go in the back.
5. Deburr inside and out. Clean with water only: solvent and flux residue poison the catalytic sensor.

**How it fits the parts next to it.**

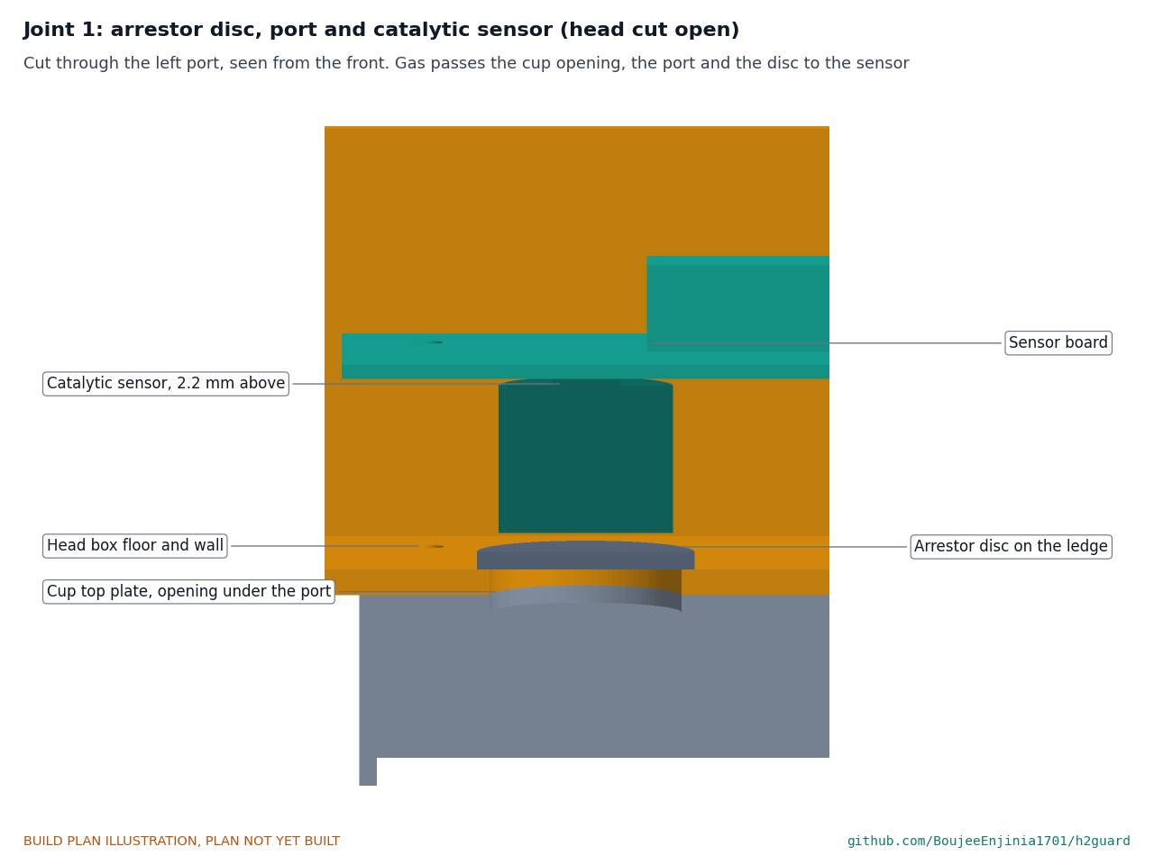
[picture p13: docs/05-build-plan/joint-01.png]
Figure 3. Joint 1: arrestor disc, port and catalytic sensor


*Figure 3. Cut through the left port. Test gas or a leak passes the opening in the cup, the 22 mm port and the 2 mm sintered disc to the sensor 2.2 mm above it.*

Each 25 mm sintered stainless disc lies on the inside of the floor over its port, resting on the 1.5 mm ledge all round, and is bonded with a bead of two-part epoxy round its edge so no gas can pass round it. Never use silicone sealant anywhere in the head: it poisons the catalytic sensor. The cup screws flat to the underside of the floor and the sensor board stands on the standoffs above the discs (section 3.2). The box hangs on the drop rod (section 3.5) with its top 85 mm below the ceiling.

**Check before moving on.** A disc laid on each port covers it with an even ledge all round; the four standoff holes line up with the holes in the cup.

### 3.2 Bump test cup, printed

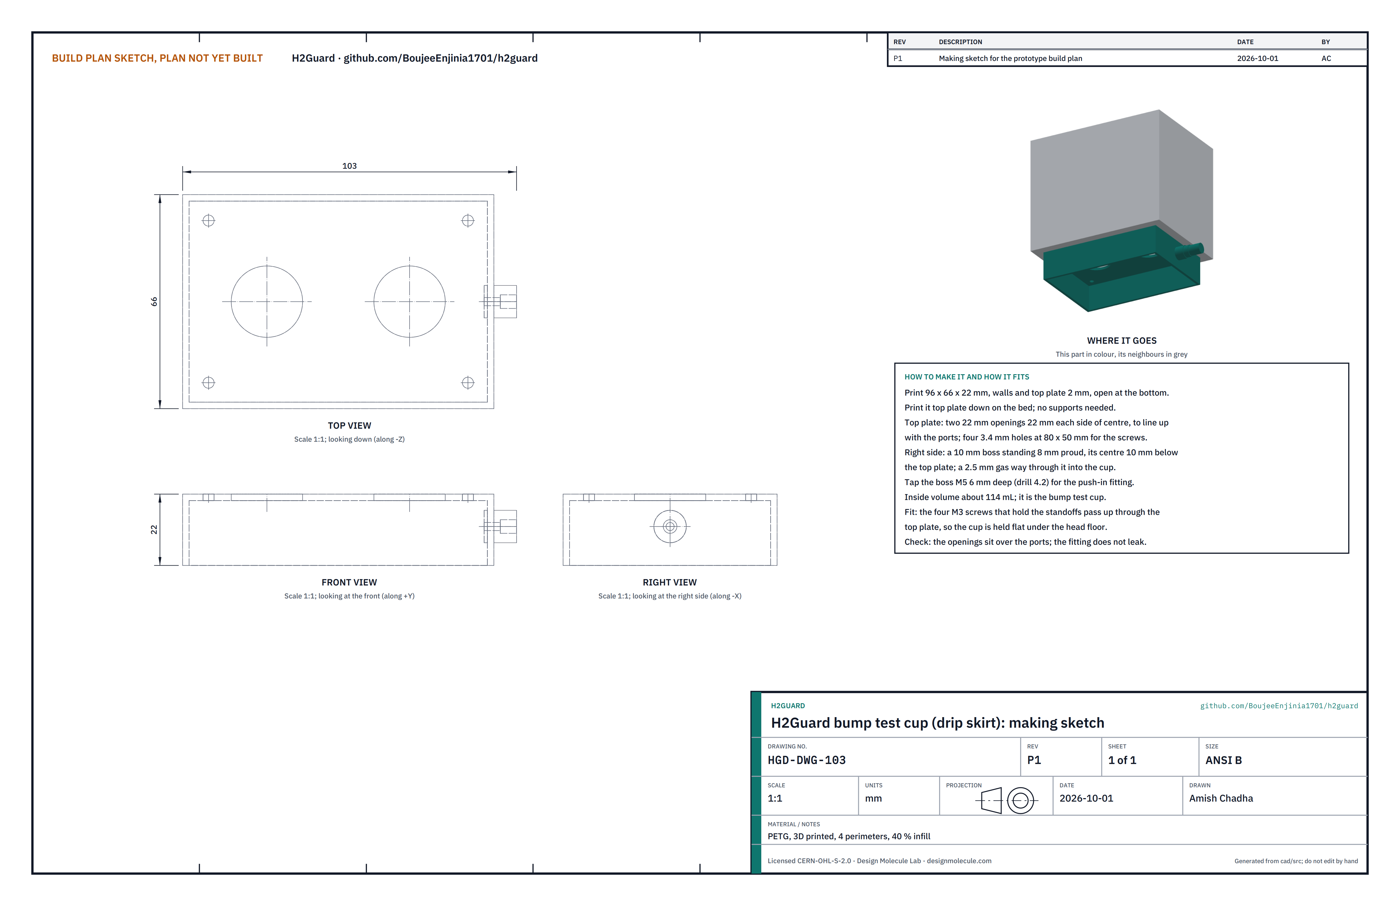
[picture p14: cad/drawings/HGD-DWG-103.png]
Figure 4. Making sketch of the bump test cup


*Figure 4. Bump test cup making sketch (HGD-DWG-103).*

**What it is and what it is made from.** The open-bottomed skirt under the head. It keeps drips off the ports and, during a bump test, holds the test gas round them. PETG, printed with four perimeters and 40 % infill.

**How to make it.**

1. Print the cup 96 x 66 x 22 mm, walls and top plate 2 mm, top plate down on the bed; no supports are needed.
2. The print carries two 22 mm openings in the top plate, 22 mm each side of the centre, and four 3.4 mm holes 80 x 50 mm apart. Check them against the head box before going on.
3. On the right side, a boss 10 mm across stands 8 mm proud, its centre 10 mm below the top face, with a 2.5 mm gas way into the cup. Tap the boss M5 6 mm deep (drill 4.2 mm first if the printed hole is undersize).
4. Screw the M5 straight push-in fitting for 4 mm tube into the boss with thread sealant tape.

**How it fits the parts next to it.**

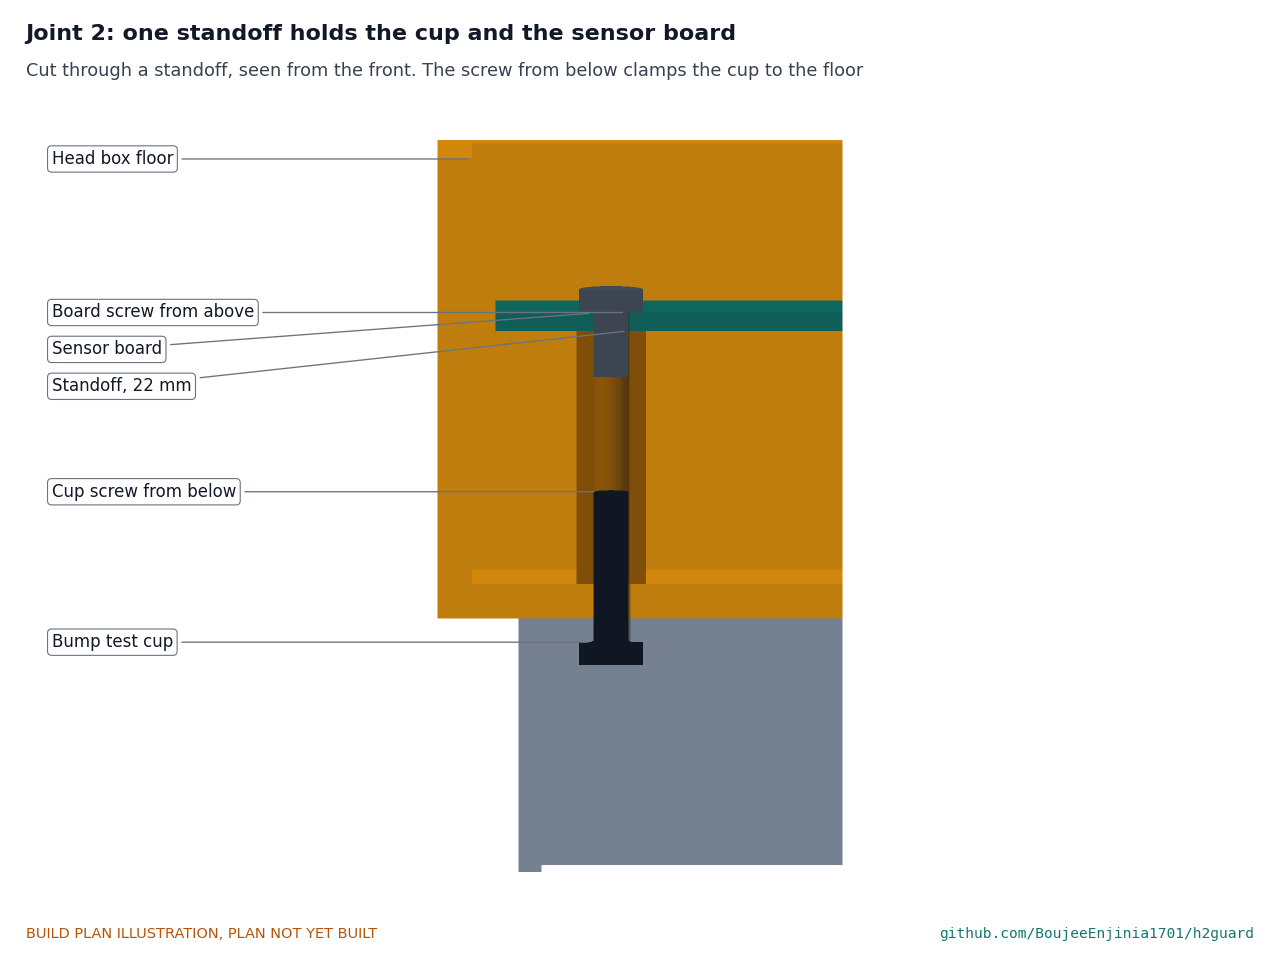
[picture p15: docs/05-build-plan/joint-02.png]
Figure 5. Joint 2: one standoff holds the cup and the sensor board


*Figure 5. Cut through a standoff. An M3 screw from inside the cup passes up through the top plate and the head floor into the standoff; the board screw goes into its other end.*

The top plate sits flat against the underside of the head floor with its openings under the ports. Four M3 screws, heads inside the cup, go up through the plate and the floor into four 22 mm M3 female standoffs standing on the inside of the floor. The cup holds about 114 mL.

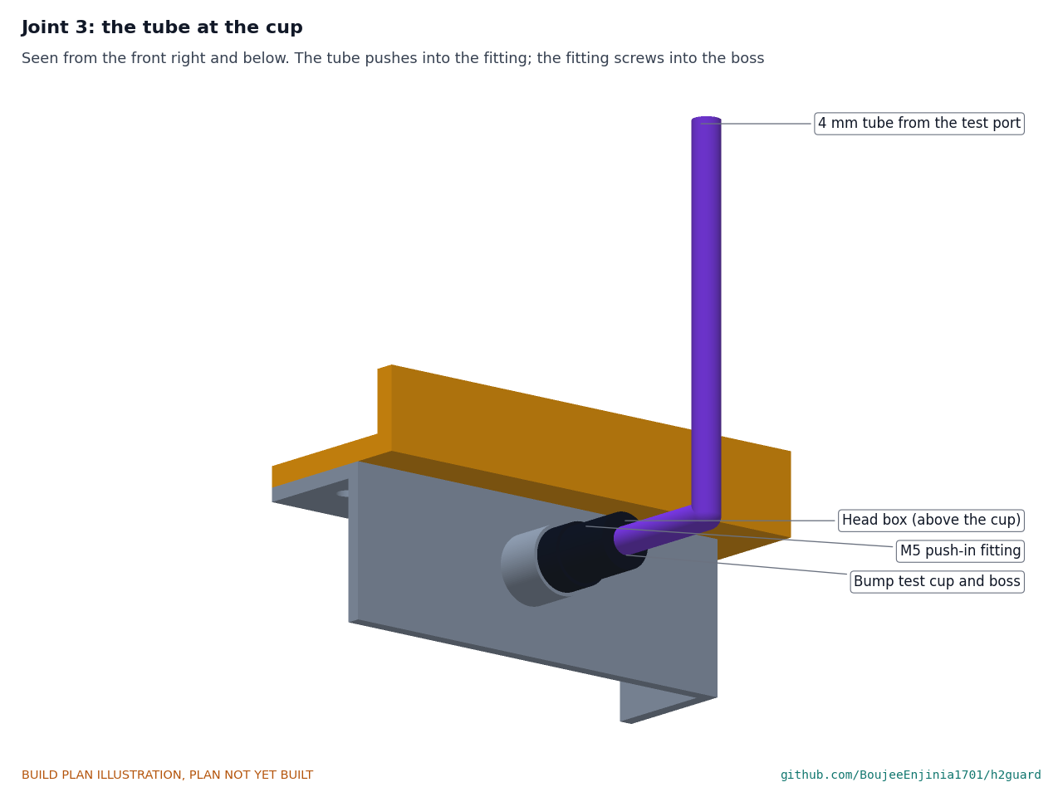
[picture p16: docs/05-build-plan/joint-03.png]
Figure 6. Joint 3: the tube at the cup


*Figure 6. The 4 mm tube pushes into the fitting on the cup's boss.*

**Check before moving on.** Blow gently through a length of 4 mm tube pushed into the fitting: air comes out of the cup, and the fitting does not leak round its thread.

### 3.3 Sensor board with both sensors

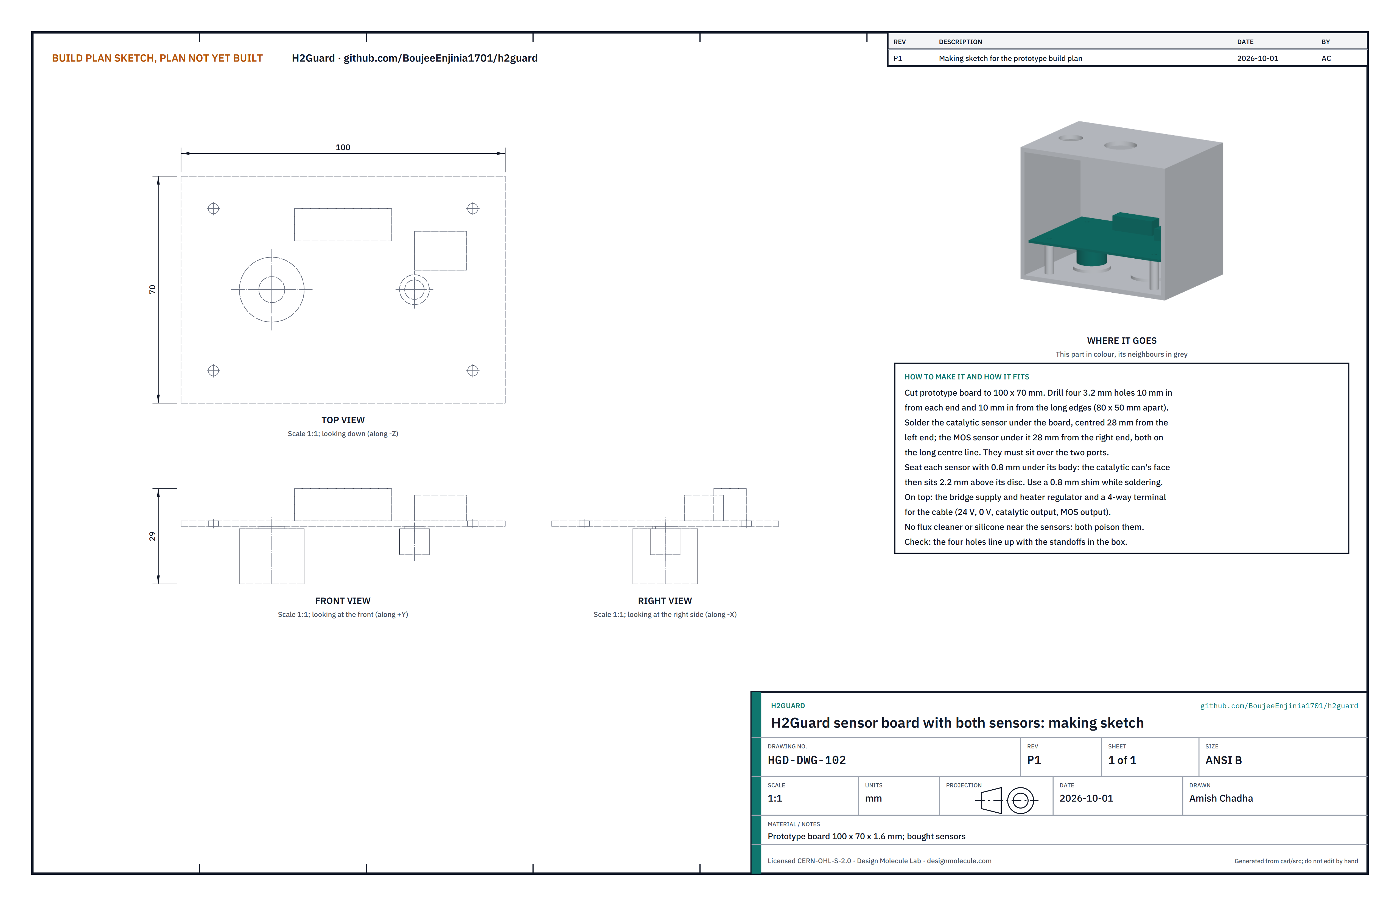
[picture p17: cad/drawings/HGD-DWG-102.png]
Figure 7. Making sketch of the sensor board


*Figure 7. Sensor board making sketch (HGD-DWG-102).*

**What it is and what it is made from.** A small board that carries the catalytic sensor and the metal oxide sensor under it, over the two ports, and their supply and output parts on top. Prototype board 100 x 70 x 1.6 mm, with the two bought sensors.

**How to make it.**

1. Cut prototype board to 100 x 70 mm. Drill four 3.2 mm holes 10 mm in from each end and 10 mm in from the long edges (80 x 50 mm apart), to match the standoffs.
2. Solder the catalytic sensor under the board on the long centre line, centred 28 mm from the left end; solder the metal oxide sensor under the board on the same line, 28 mm from the right end. They must sit over the left and right ports.
3. Seat each sensor 0.8 mm under the board, using a 0.8 mm shim while soldering. The catalytic sensor's face then sits 2.2 mm above its disc, which keeps the gas delay through the disc to about 1.5 s.
4. On top, build the bridge supply for the catalytic sensor, the heater supply and load resistor for the metal oxide sensor, and a 4-way screw terminal for the cable (24 V, 0 V, catalytic output, metal oxide output), following each sensor maker's application note.
5. Do not use flux cleaner, silicone or solvent near the sensors.

**How it fits the parts next to it.** The board stands on the four standoffs (Figure 5) and is held by four M3 screws from above. It goes in through the open front of the head box before the lid is fitted. The cable comes in through the gland in the top of the box to the 4-way terminal.

**Check before moving on.** With the board on its standoffs, each sensor sits centred over its port and the catalytic sensor's face is 2 to 2.5 mm above its disc (measure with feeler gauges through the open front).

### 3.4 Ceiling drop rod

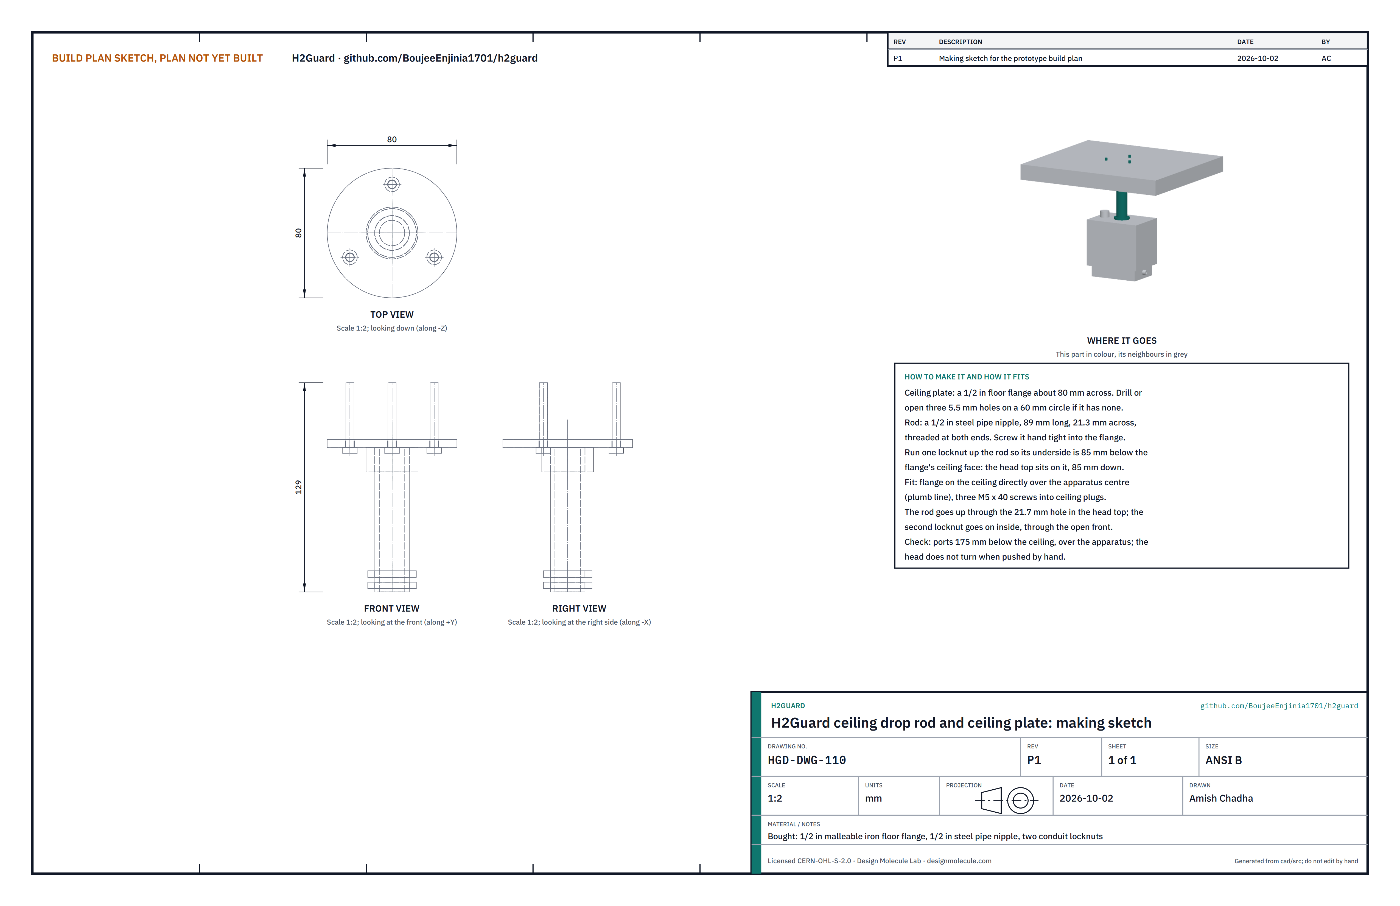
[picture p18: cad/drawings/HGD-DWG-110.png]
Figure 8. Making sketch of the ceiling drop rod


*Figure 8. Ceiling drop rod and ceiling plate making sketch (HGD-DWG-110).*

**What it is and what it is made from.** The short rod that hangs the detector head from the ceiling directly over the apparatus. A bought 1/2 in malleable iron floor flange about 80 mm across serves as the ceiling plate; a 1/2 in steel pipe nipple 89 mm long (21.3 mm across) is the rod; two 1/2 in conduit locknuts clamp the top of the head box between them.

**How to make it.**

1. If the flange has no screw holes, drill three 5.5 mm holes on a 60 mm circle.
2. Screw the nipple hand tight into the flange, then a quarter turn with a pipe wrench.
3. Run one locknut up the nipple so its underside is 85 mm below the face of the flange that goes against the ceiling. The head's top sits on it.

**How it fits the parts next to it.**

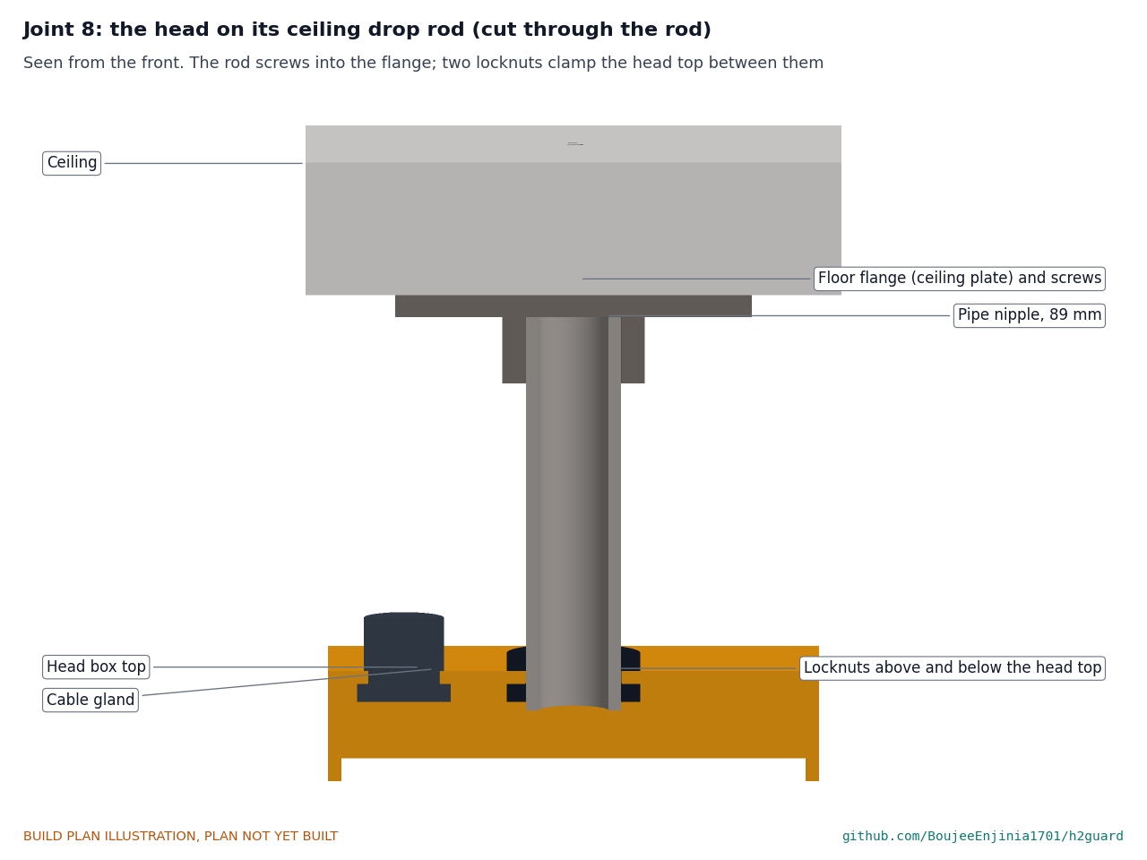
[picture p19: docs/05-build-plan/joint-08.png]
Figure 9. Joint 8: the head on its ceiling drop rod


*Figure 9. Cut through the rod. The rod screws into the flange on the ceiling; the head's top is clamped between the two locknuts.*

Find the apparatus centre on the ceiling with a plumb line and fix the flange there with three M5 x 40 screws into ceiling plugs. The rod passes up through the 21.7 mm hole in the head's top; the second locknut goes on inside the box through its open front (step 4). The cable gland sits 38 mm to the left of the rod, so the cable runs along the ceiling to it.

**Check before moving on.** The rod hangs plumb, the flange sits flat on the ceiling, and with the head fitted its sensor ports are 175 mm below the ceiling, give or take 10 mm, and over the apparatus centre.

### 3.5 Controller box, drilled

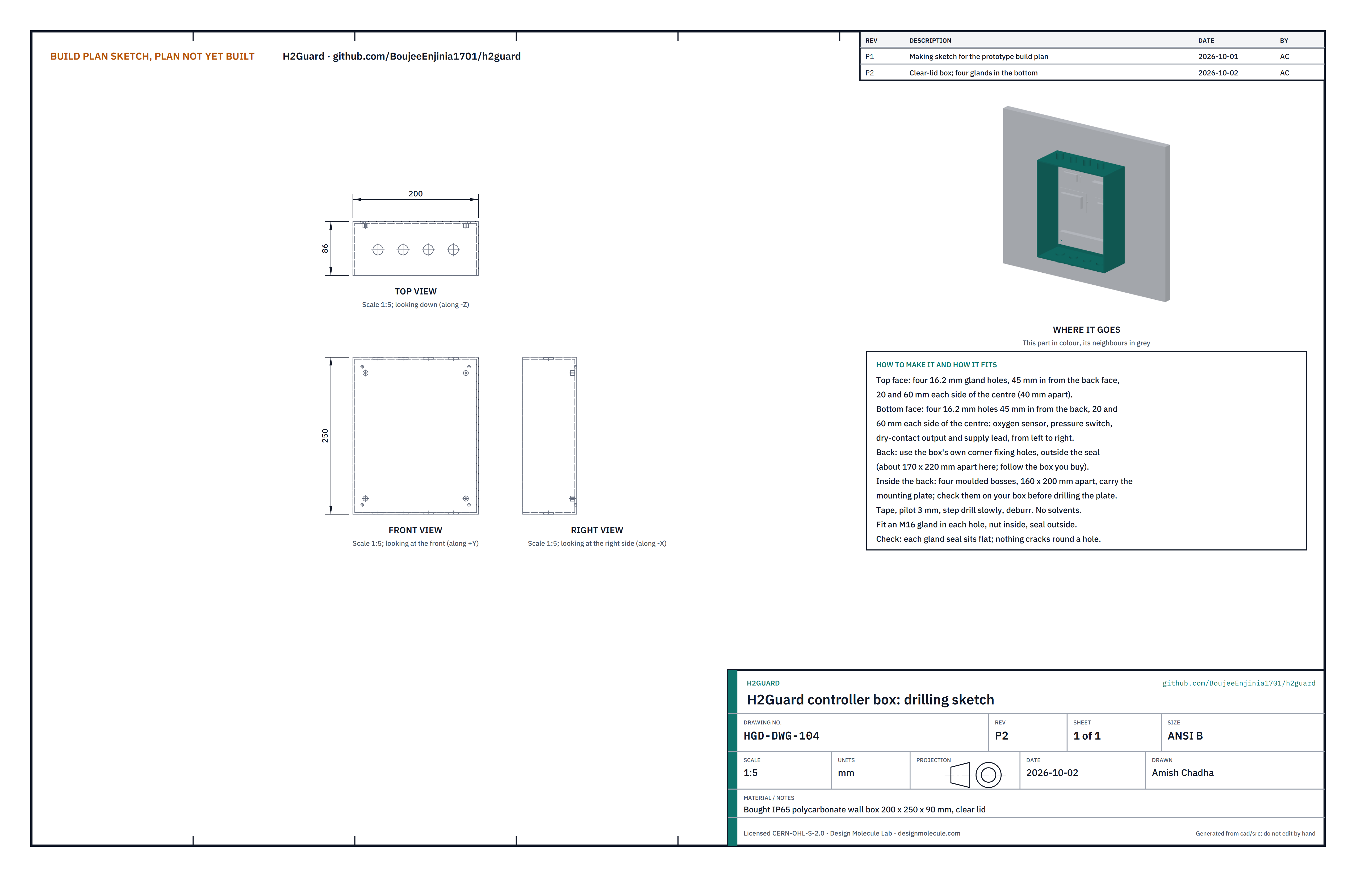
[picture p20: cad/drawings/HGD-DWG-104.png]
Figure 10. Drilling sketch of the controller box


*Figure 10. Controller box drilling sketch (HGD-DWG-104).*

**What it is and what it is made from.** The wall box that holds the electronics. A bought IP65 polycarbonate box 200 wide, 250 tall and 90 deep with a clear lid on the front, four moulded bosses inside the back and fixing holes at the back corners outside the seal.

**How to make it.**

1. Tape the top and bottom faces and mark the holes.
2. Top: four 16.2 mm holes 45 mm in from the back face, 20 and 60 mm each side of the centre (40 mm apart), for the cables from the head, fan, valve and beacon.
3. Bottom: four 16.2 mm holes 45 mm in from the back face, 20 and 60 mm each side of the centre: from left to right, the oxygen sensor, the pressure switch, the dry-contact output and the supply lead. Leave the left one plugged if the oxygen sensor is not fitted.
4. Pilot drill 3 mm, open with a step drill slowly, deburr. No solvents: polycarbonate crazes.
5. Fit an M16 cable gland in each hole, seal outside, nut inside.
6. Measure the four bosses inside the back (the model assumes 160 mm apart across and 200 mm apart up and down) and note the result for the mounting plate.

**How it fits the parts next to it.** The back sits flat on the wall, top 1,475 mm above the floor (1,025 mm below the ceiling), on four screws with wall plugs through the corner fixing holes. The mounting plate sits on the bosses inside (Figure 12) and the lid closes the front (section 3.7).

**Check before moving on.** Every gland seal sits flat and no crack runs from any hole under a bright lamp.

### 3.6 Controller mounting plate and modules

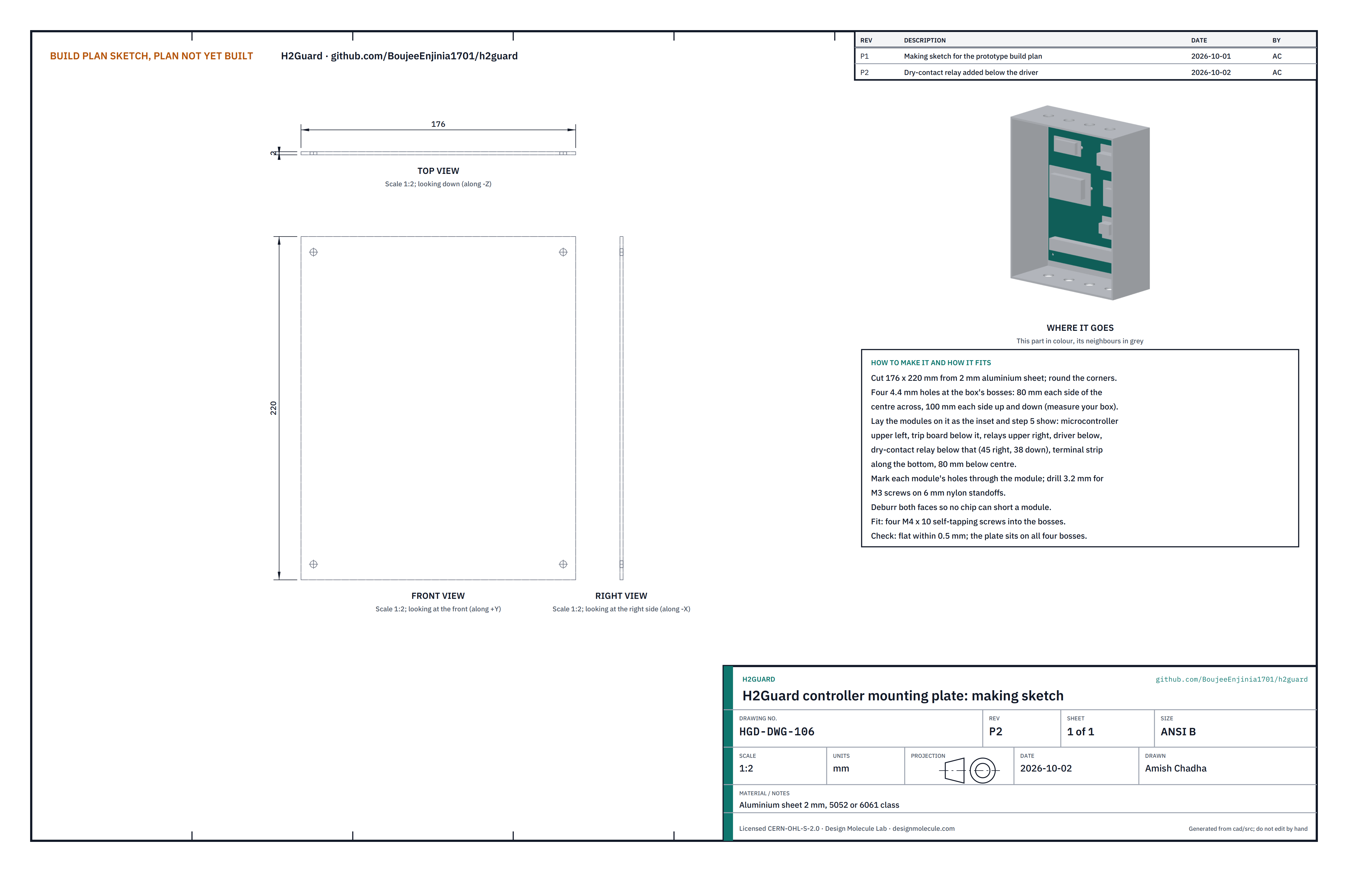
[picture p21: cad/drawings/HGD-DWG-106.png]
Figure 11. Making sketch of the controller mounting plate


*Figure 11. Controller mounting plate making sketch (HGD-DWG-106).*

**What it is and what it is made from.** The flat plate inside the controller box that carries the bought modules, the hand-built trip board, the dry-contact relay and the terminal strip. Aluminium sheet 2 mm, 5052 or 6061 class, 176 x 220 mm.

**How to make it.**

1. Cut the plate to 176 x 220 mm and round the corners to about 3 mm.
2. Drill four 4.4 mm holes at the boss positions you measured (the model has them 80 mm each side of the centre across and 100 mm each side up and down).
3. Lay out the modules on the front face as Figure 12 shows: microcontroller module upper left, trip board below it, relay module upper right, valve and alarm driver below it, the dry-contact relay with its 2-way output terminal below the driver (45 mm right of and 38 mm below the centre), terminal strip along the bottom, 80 mm below the centre.
4. Mark each module's mounting holes through the module, drill 3.2 mm, and fit each module on M3 screws with 6 mm nylon standoffs. Fit the terminal strip directly to the plate.
5. Deburr both faces so no chip can short a module.
6. Wire the modules as Figure 13 shows (section 3.6.1).

**How it fits the parts next to it.**

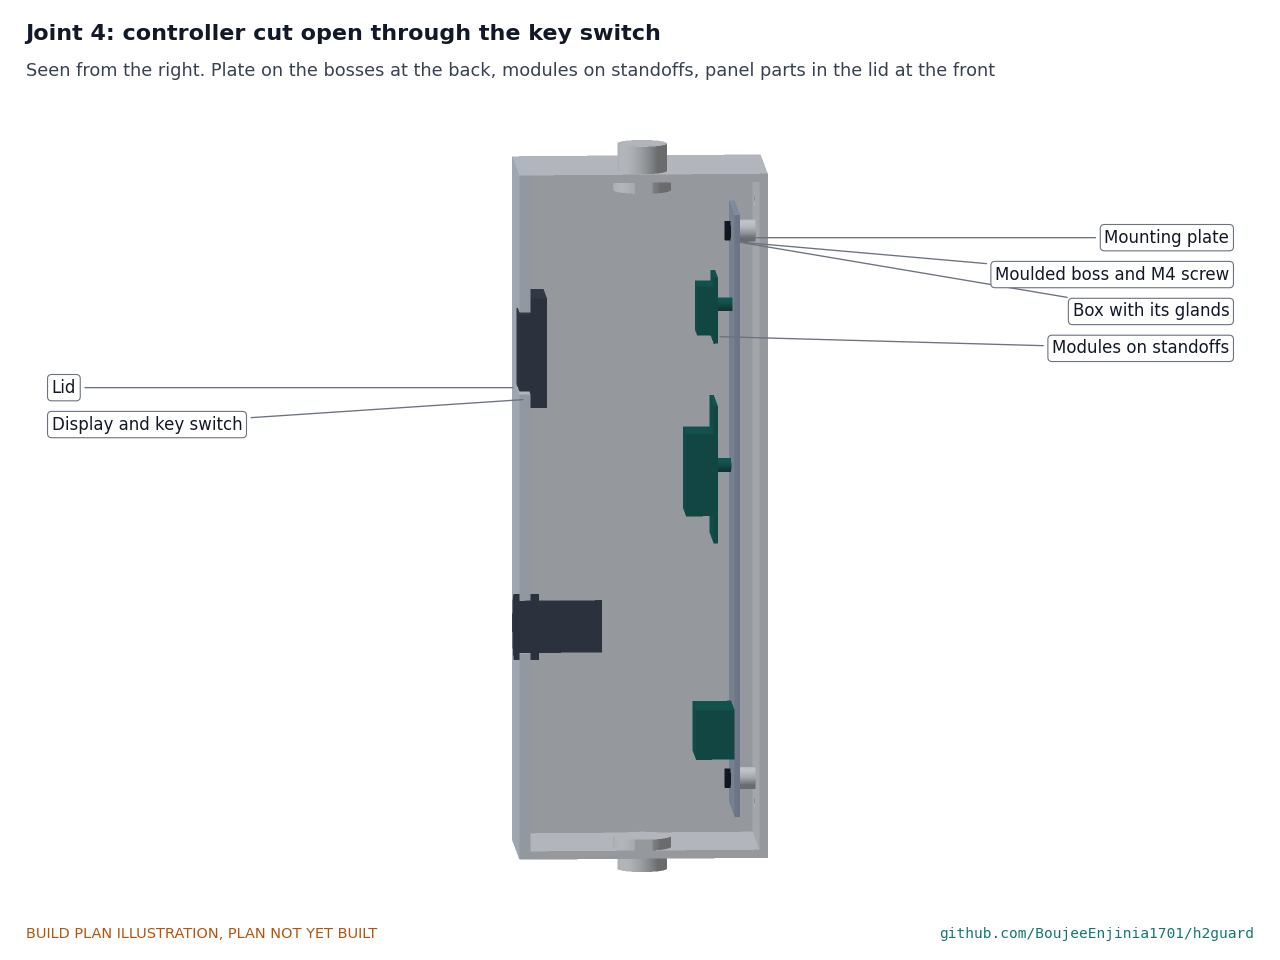
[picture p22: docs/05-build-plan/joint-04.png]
Figure 12. Joint 4: controller cut open through the key switch


*Figure 12. The plate sits on the four moulded bosses at the back of the box; the modules stand 6 mm off it; the display and key switch are in the lid at the front, well clear of the modules.*

The plate lies flat on the four bosses, held by four M4 x 10 self-tapping screws. Its front face is 9 mm in front of the inside of the back wall, and the deepest module stands about 23 mm in front of the plate, leaving about 25 mm to the back of the key switch in the lid.

**Check before moving on.** The plate is flat within 0.5 mm and sits on all four bosses without rocking.

#### 3.6.1 Wiring

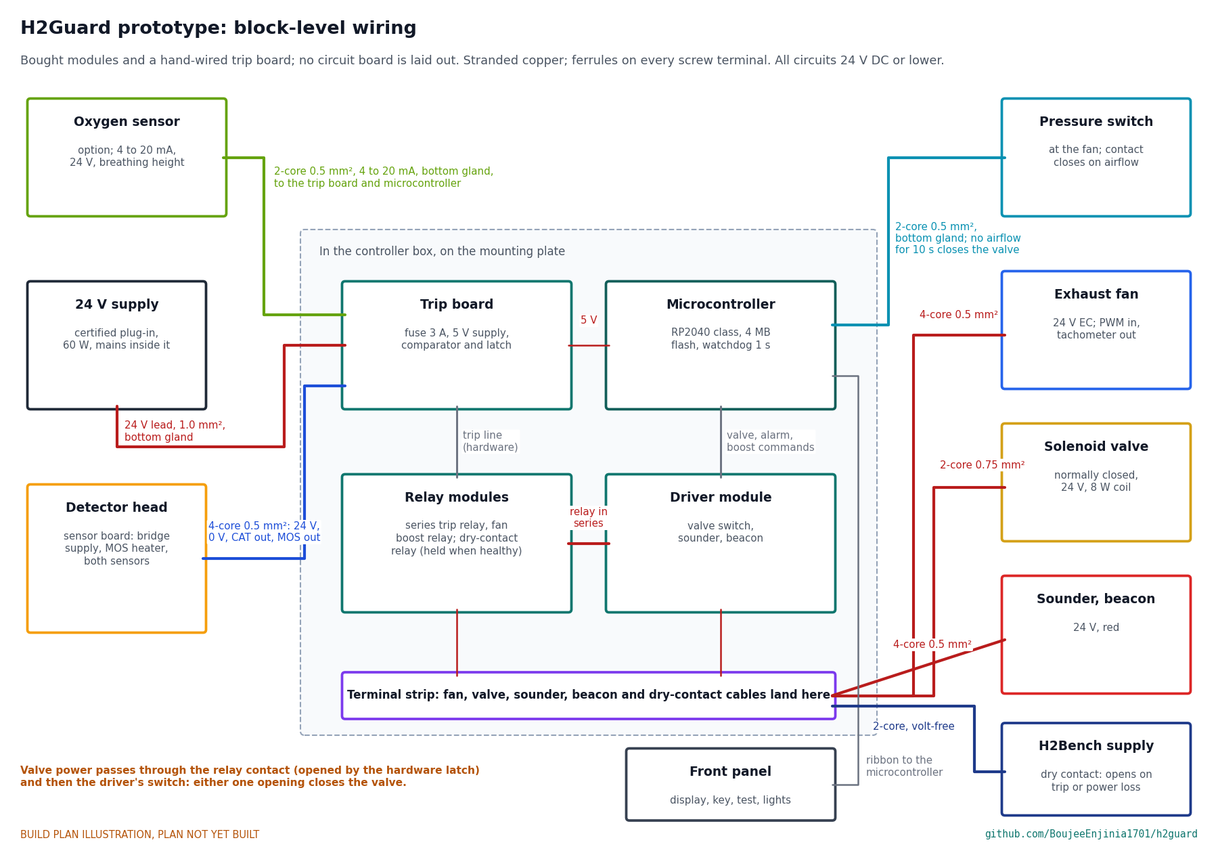
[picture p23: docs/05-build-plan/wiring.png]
Figure 13. Block-level wiring


*Figure 13. Block-level wiring with wire sizes. No circuit board is laid out at this stage; bought modules and a hand-wired trip board stand in for the controller board.*

The controller board in the bill of materials is a custom board, which is TRL 4 work. For this prototype, buy or build these:

*Table 2. Modules that stand in for the controller board.*

| Module | What to buy or build |
| --- | --- |
| Microcontroller | RP2040-class module with 4 MB of flash or more and a hardware watchdog |
| Trip board | Hand-wired on prototype board: input fuse about 3 A, 5 V supply from 24 V, the catalytic sensor input, a window comparator that trips above the 25 % LFL level or when the input reads open or shorted, a latch that only the key resets, and a 150 ohm resistor that turns the oxygen sensor's 4 to 20 mA signal into a voltage for the microcontroller |
| Relay module | Two relays with 24 V coils: the series trip relay, opened by the latch, and the fan boost relay |
| Dry-contact relay | One relay with a 24 V coil and a changeover contact rated 2 A at 30 V DC, held energized while all is well, with a 2-way screw terminal for the output |
| Driver module | Low-side switches for the valve coil (with a Zener clamp for fast closing), the sounder and the beacon, driven by the microcontroller |
| Terminal strip | 5.08 mm pitch screw terminals for every field cable |

Wire it like this, with stranded copper and a ferrule on every screw terminal:

1. Supply lead from the 24 V unit through the bottom gland to the trip board's fused input: 1.0 mm² (17 AWG).
2. Trip board 5 V output to the microcontroller module: 0.5 mm² (20 AWG).
3. Head cable, 4-core 0.5 mm², through a top gland to the trip board: 24 V, 0 V, catalytic output, metal oxide output.
4. Valve coil supply from the terminal strip through the series trip relay contact and then the driver's valve switch: 0.75 mm² (18 AWG). Either one opening closes the valve.
5. Fan cable, 4-core 0.5 mm², from the terminal strip: 24 V, 0 V, speed signal and tachometer.
6. Sounder and beacon cable, 4-core 0.5 mm², from the terminal strip.
7. Front panel parts to the microcontroller with a short ribbon cable, 0.14 mm².
8. Pressure switch cable, 2-core 0.5 mm², through a bottom gland to a microcontroller input. With the fan running, if the switch has not closed for 10 s, the microcontroller closes the valve, latches and shows the fault.
9. Dry-contact output cable, 2-core 0.5 mm², from the dry-contact relay's terminal through a bottom gland to the host bench. The relay is held energized while all is well, so its contact opens on a trip, a fault or loss of power.
10. Oxygen sensor cable (if fitted), 2-core 0.5 mm², through a bottom gland to the trip board's 4 to 20 mA input. Below 19.5 % oxygen the controller warns; below 18 % it closes the valve and latches.

**Check before moving on.** Every wire continues end to end; with the supply unplugged, no 24 V terminal reads short to 0 V; every wire is labelled at both ends.

### 3.7 Controller lid with the front panel

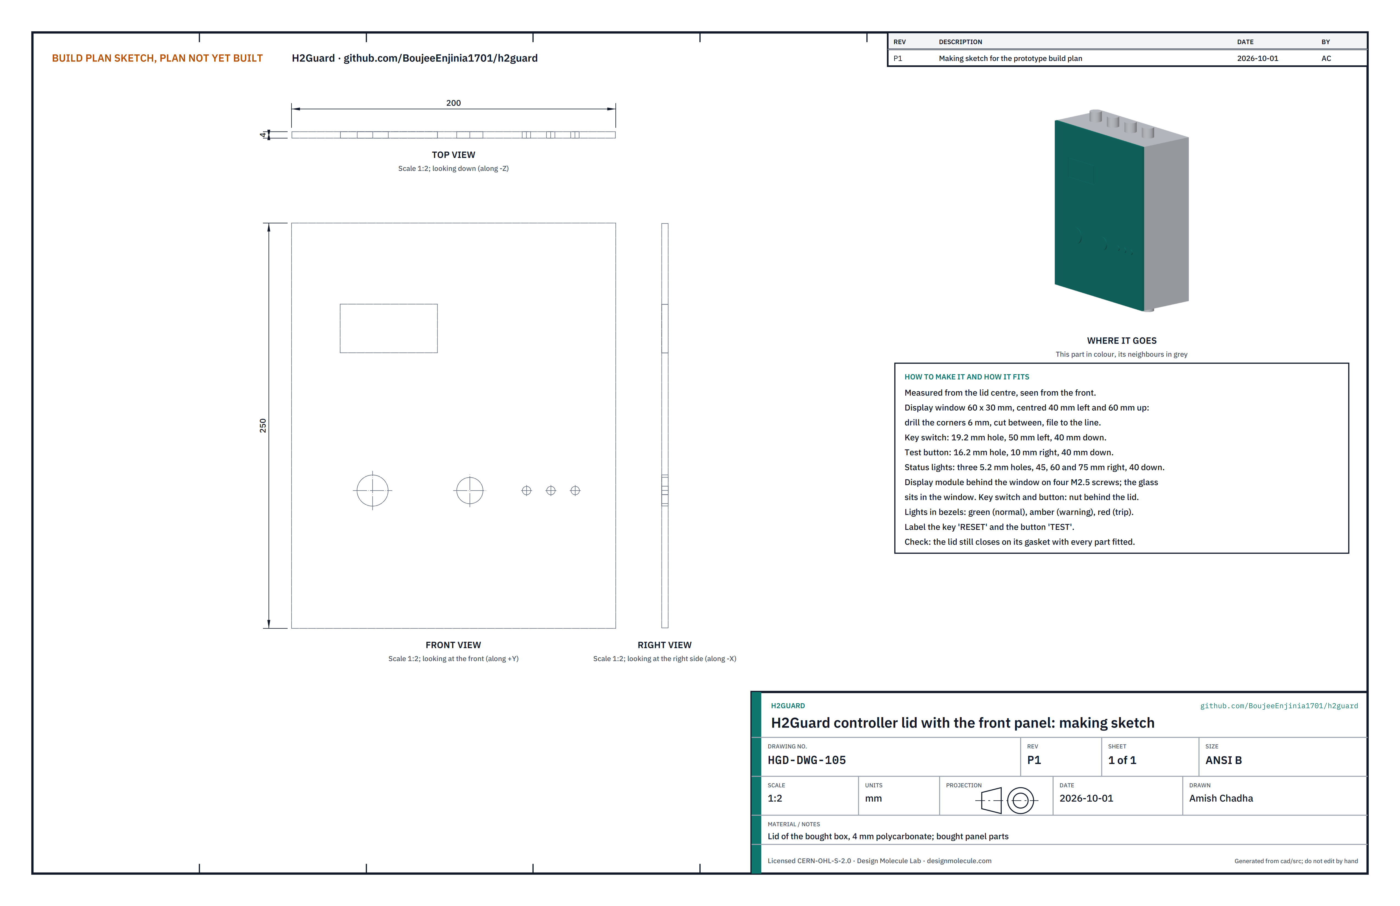
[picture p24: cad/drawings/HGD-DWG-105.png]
Figure 14. Making sketch of the controller lid


*Figure 14. Controller lid making sketch (HGD-DWG-105).*

**What it is and what it is made from.** The box's own clear 4 mm polycarbonate lid, cut to take the display, the key-switch reset, the test button and three status lights.

**How to make it.** All positions are from the lid centre, seen from the front.

1. Display window 60 x 30 mm, centred 40 mm left and 60 mm up: drill a 6 mm hole in each corner, cut between them and file to the line.
2. Key switch: 19.2 mm hole, 50 mm left and 40 mm down.
3. Test button: 16.2 mm hole, 10 mm right and 40 mm down.
4. Status lights: three 5.2 mm holes, 45, 60 and 75 mm right and 40 mm down.
5. Fit the display module behind the window on four M2.5 screws, the glass in the window. Fit the key switch and button through their holes with their nuts behind the lid, and the lights in bezels: green (normal), amber (warning), red (trip).
6. Label the key RESET and the button TEST.

**How it fits the parts next to it.** The lid closes on the box's gasket with its own captive screws; the panel parts reach about 26 mm into the box, clear of the modules (Figure 12).

**Check before moving on.** The lid closes evenly on its gasket with every part fitted.

### 3.8 Bump test port bracket

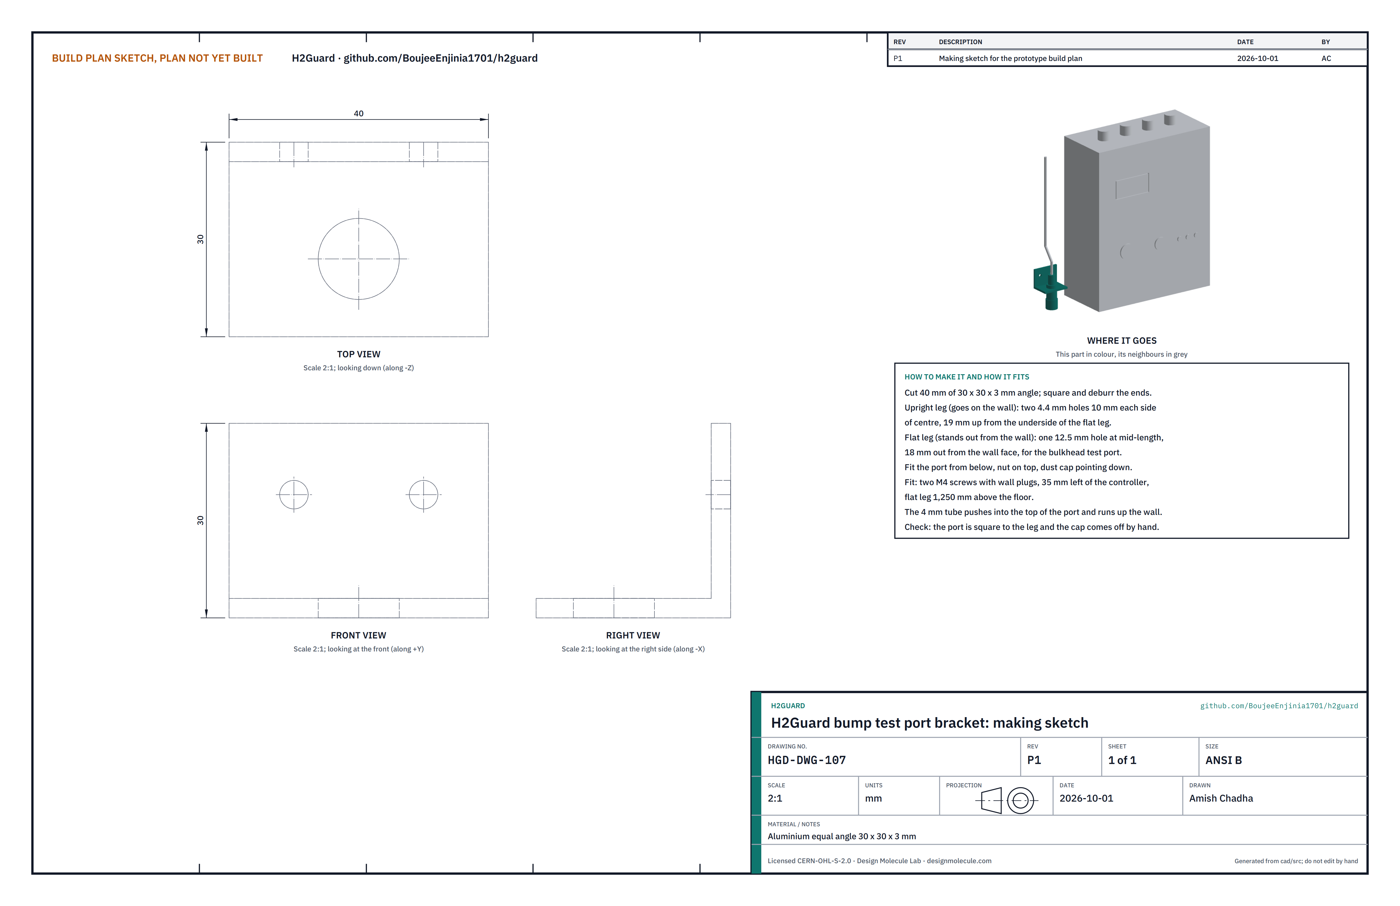
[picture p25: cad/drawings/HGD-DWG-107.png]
Figure 15. Making sketch of the test port bracket


*Figure 15. Test port bracket making sketch (HGD-DWG-107).*

**What it is and what it is made from.** A short angle that holds the capped test port on the wall beside the controller. Aluminium equal angle 30 x 30 x 3 mm, 40 mm long.

**How to make it.**

1. Cut 40 mm of angle; square and deburr the ends.
2. Upright leg (goes on the wall): two 4.4 mm holes 10 mm each side of the centre, 19 mm up from the underside of the flat leg.
3. Flat leg (stands out from the wall): one 12.5 mm hole at mid-length, 18 mm out from the wall face.
4. Fit the bulkhead test port up through the flat leg, nut on top, dust cap underneath.

**How it fits the parts next to it.**

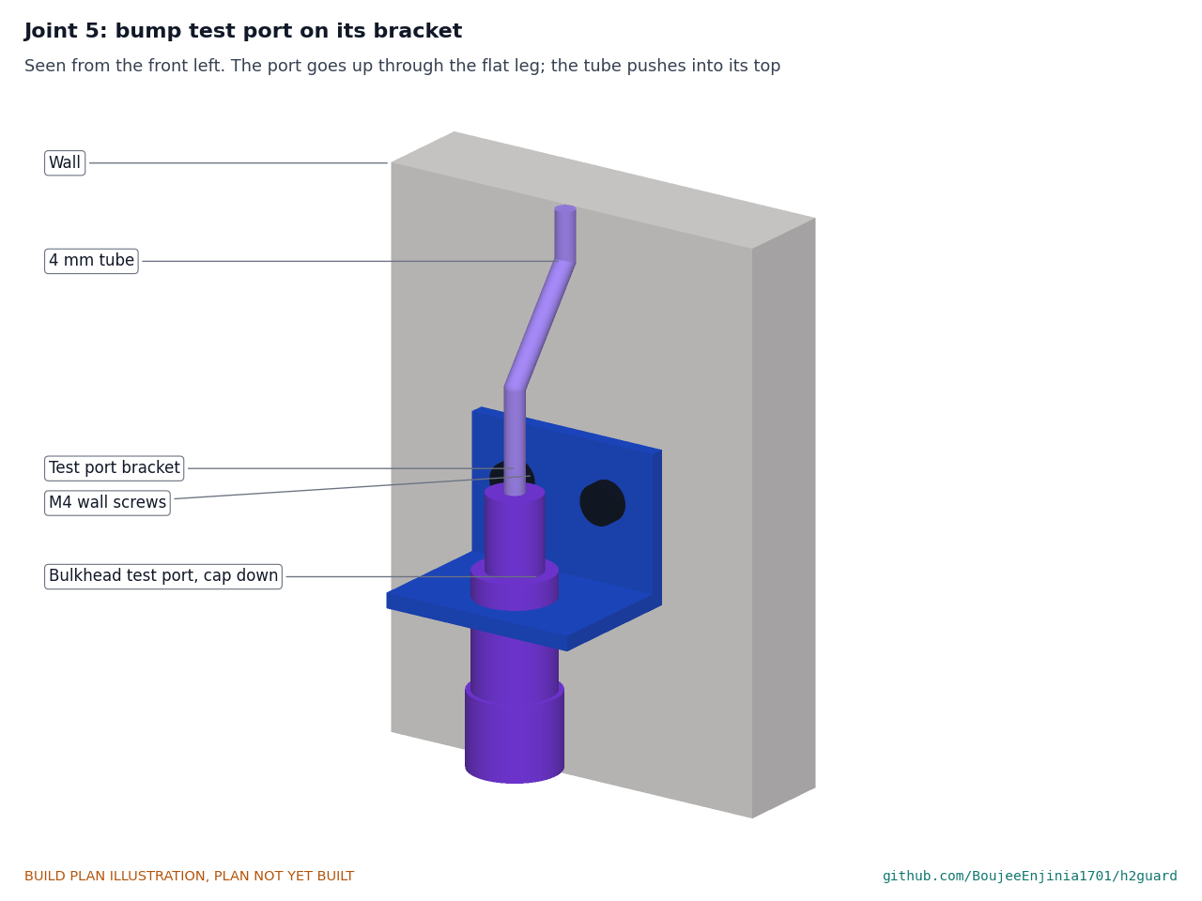
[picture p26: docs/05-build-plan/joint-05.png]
Figure 16. Joint 5: test port on its bracket


*Figure 16. The port goes up through the flat leg; the tube pushes into its top.*

The upright leg sits flat on the wall 35 mm left of the controller, with the flat leg 1,250 mm above the floor, on two M4 screws with wall plugs. Test gas connects to the port from below; the 4 mm tube leaves its top and runs up the wall.

**Check before moving on.** The port is square to the leg and the dust cap comes off by hand.

### 3.9 Fan plate

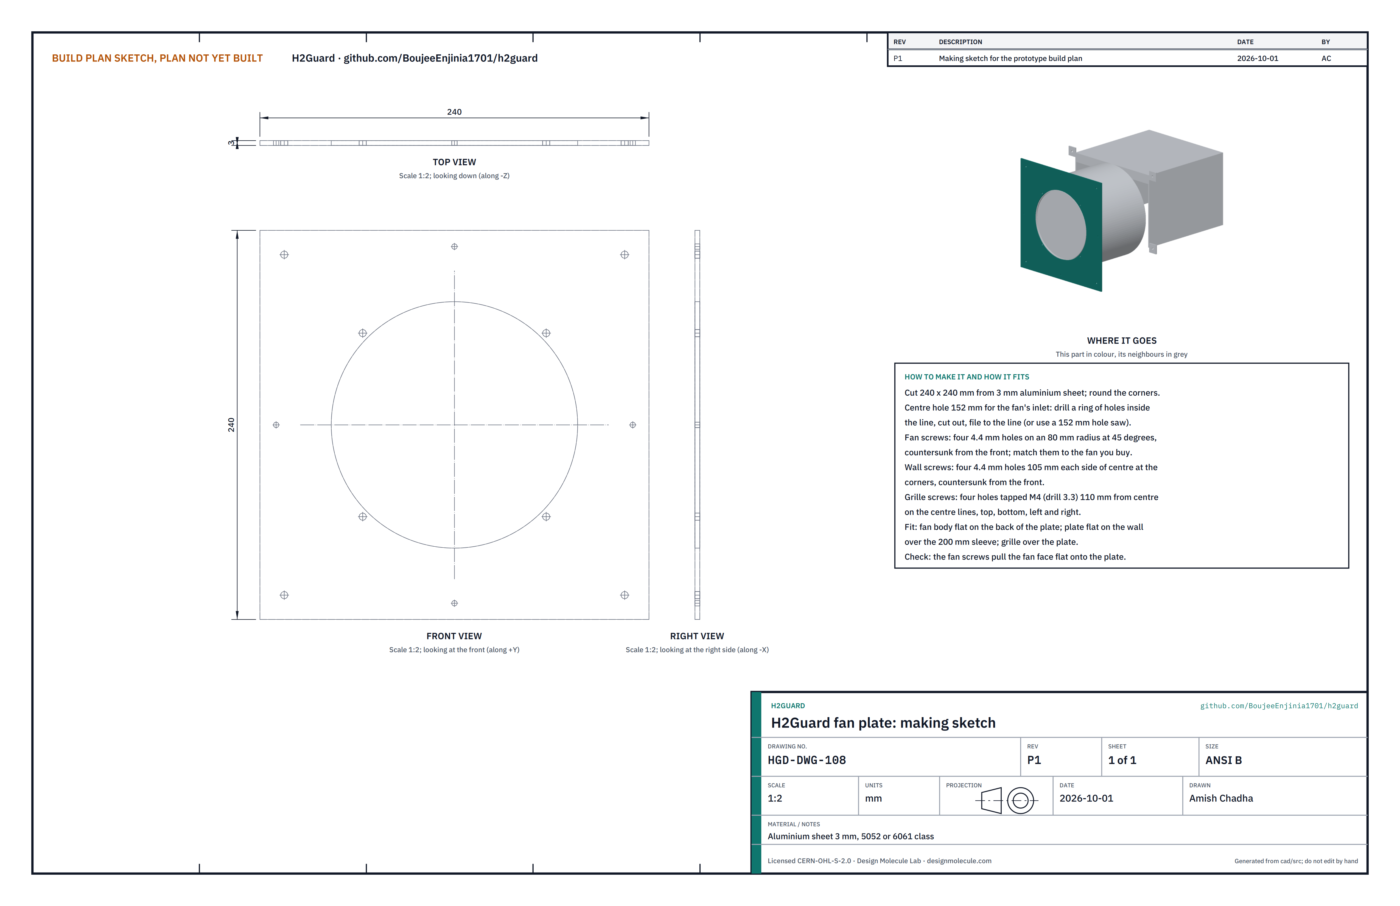
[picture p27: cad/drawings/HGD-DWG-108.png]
Figure 17. Making sketch of the fan plate


*Figure 17. Fan plate making sketch (HGD-DWG-108).*

**What it is and what it is made from.** A square plate on the inside wall face that holds the exhaust fan in its wall sleeve and carries the inside grille. Aluminium sheet 3 mm, 5052 or 6061 class, 240 x 240 mm.

**How to make it.**

1. Cut the plate to 240 x 240 mm and round the corners.
2. Cut a 152 mm centre hole for the fan's inlet: drill a ring of holes just inside the line, cut out and file to the line, or use a 152 mm hole saw.
3. Fan screws: four 4.4 mm holes on an 80 mm radius at 45° to the centre lines, countersunk from the front. Match them to the fixing holes in the inlet face of the fan you buy.
4. Wall screws: four 4.4 mm holes 105 mm each side of the centre (near the corners), countersunk from the front.
5. Grille screws: four holes tapped M4 (drill 3.3 mm), 110 mm from the centre on the centre lines (top, bottom, left and right).

**How it fits the parts next to it.**

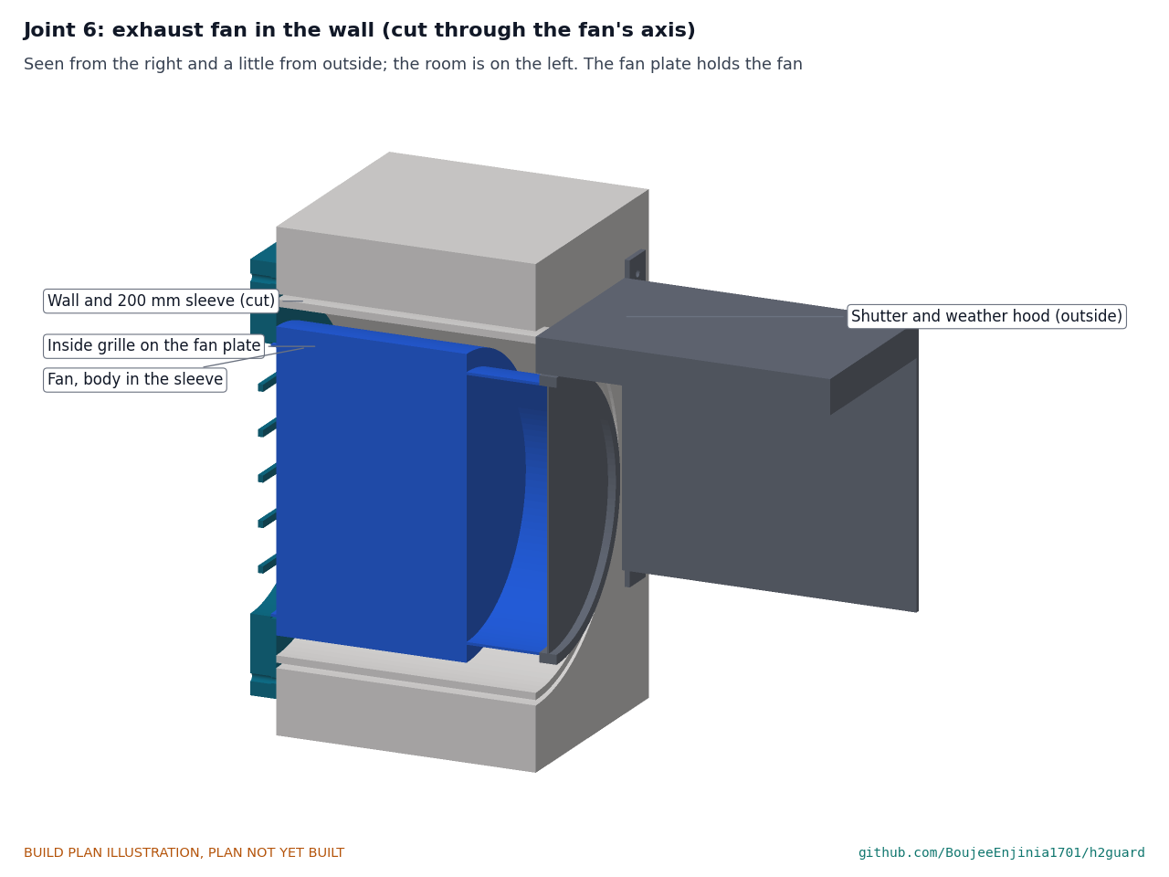
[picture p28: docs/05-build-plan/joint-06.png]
Figure 18. Joint 6: exhaust fan in the wall


*Figure 18. Cut through the fan's axis. The fan body sits in the 200 mm sleeve, its inlet face flat on the back of the plate; the grille covers the plate; the shutter and hood are outside.*

The fan's inlet face sits flat on the back of the plate, held by four M4 countersunk screws from the front. The plate sits flat on the inside wall face over the 200 mm sleeve, centred 2,300 mm above the floor, on four countersunk screws with wall plugs. The inside grille screws to the plate's tapped holes. The fan body stands 11 mm clear of the sleeve all round.

**Check before moving on.** The four fan screws pull the fan face flat onto the plate, and the fan turns freely by hand.

**The pressure switch beside the fan.** A bought low-range air pressure switch, about 85 x 85 x 55 mm with its two ports underneath, goes on the wall to the left of the fan plate, its centre 230 mm left of the fan's centre and 30 mm above it, on two screws with plugs. A 6 mm tube from its low port runs down 37 mm, across in front of the grille and into the grille opening, 62 mm below the fan's centre, ending just inside the grille in the fan's inlet. The high port stays open to the room. Air drawn into the fan lowers the pressure at the tube's end by about 6 Pa at the continuous flow and 30 Pa on boost; with no flow, whether the fan has stopped, the duct is blocked or the shutter is stuck, the difference falls to about zero. Set the switch to close at about 3 Pa.

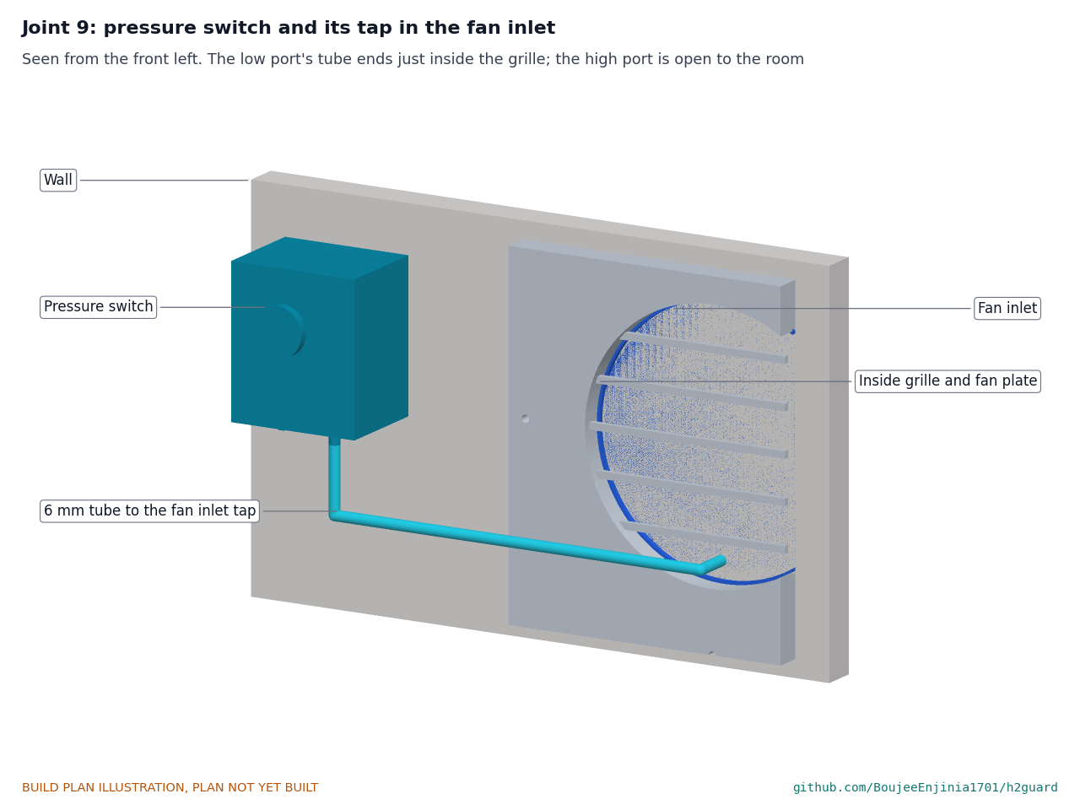
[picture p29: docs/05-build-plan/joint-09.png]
Figure 19. Joint 9: pressure switch and its tap in the fan inlet


*Figure 19. The tube from the switch's low port ends just inside the grille; the other port is open to the room.*

### 3.10 Valve bracket

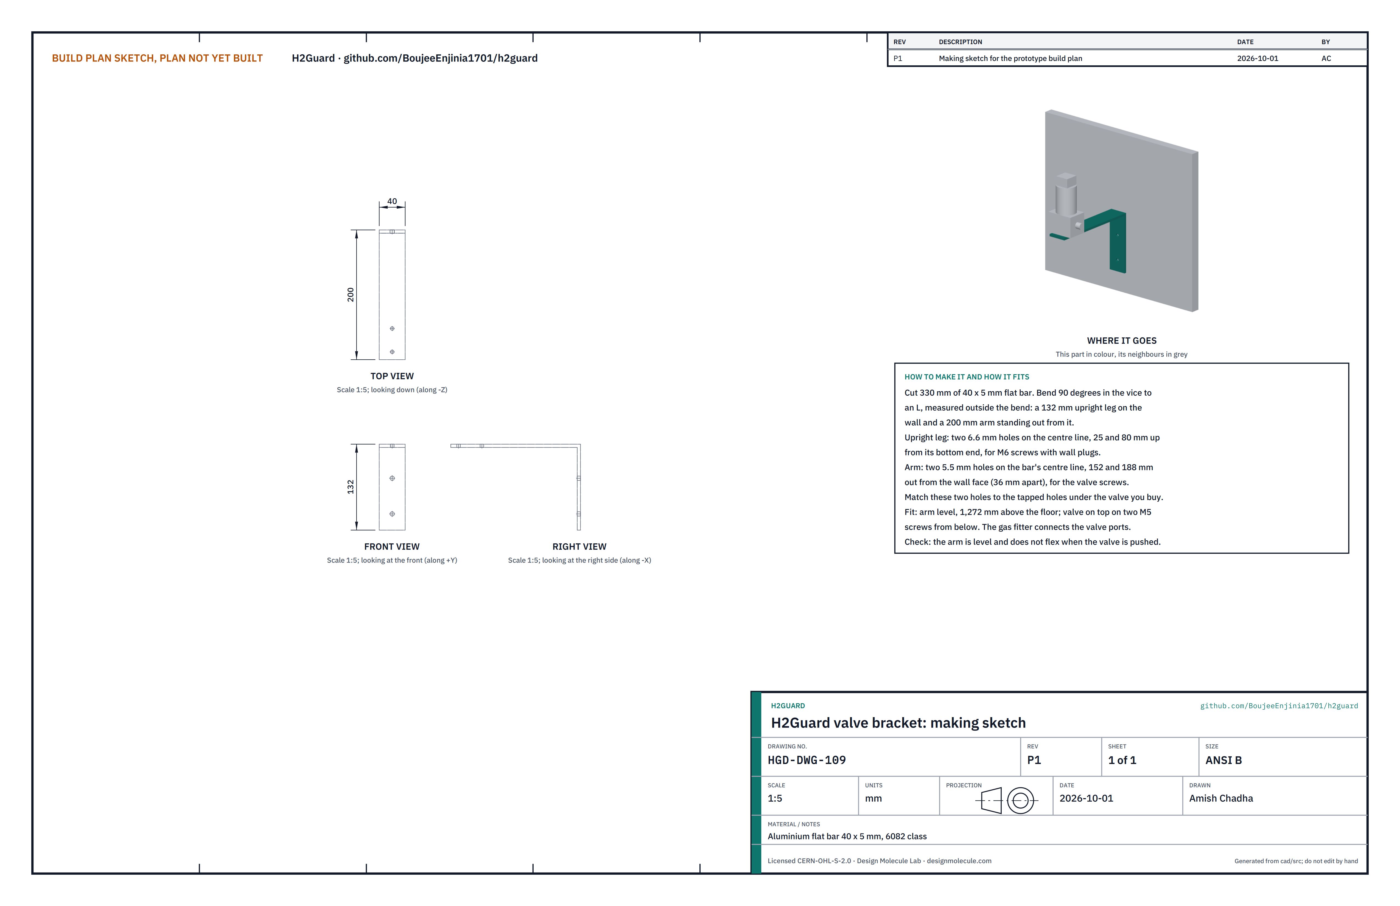
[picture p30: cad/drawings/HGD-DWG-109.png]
Figure 20. Making sketch of the valve bracket


*Figure 20. Valve bracket making sketch (HGD-DWG-109).*

**What it is and what it is made from.** An L-shaped bracket that holds the solenoid valve off the wall, in line with the supply. Aluminium flat bar 40 x 5 mm, 6082 class.

**How to make it.**

1. Cut 330 mm of bar. Bend it 90° in the vice to an L, measured outside the bend: a 132 mm leg for the wall and a 200 mm arm. Bend slowly round a radiused jaw so the outside of the bend does not crack.
2. Wall leg: two 6.6 mm holes on the centre line, 25 and 80 mm up from its bottom end.
3. Arm: two 5.5 mm holes on the centre line, 152 and 188 mm out from the wall face (36 mm apart). Match them to the tapped holes under the valve you buy.

**How it fits the parts next to it.**

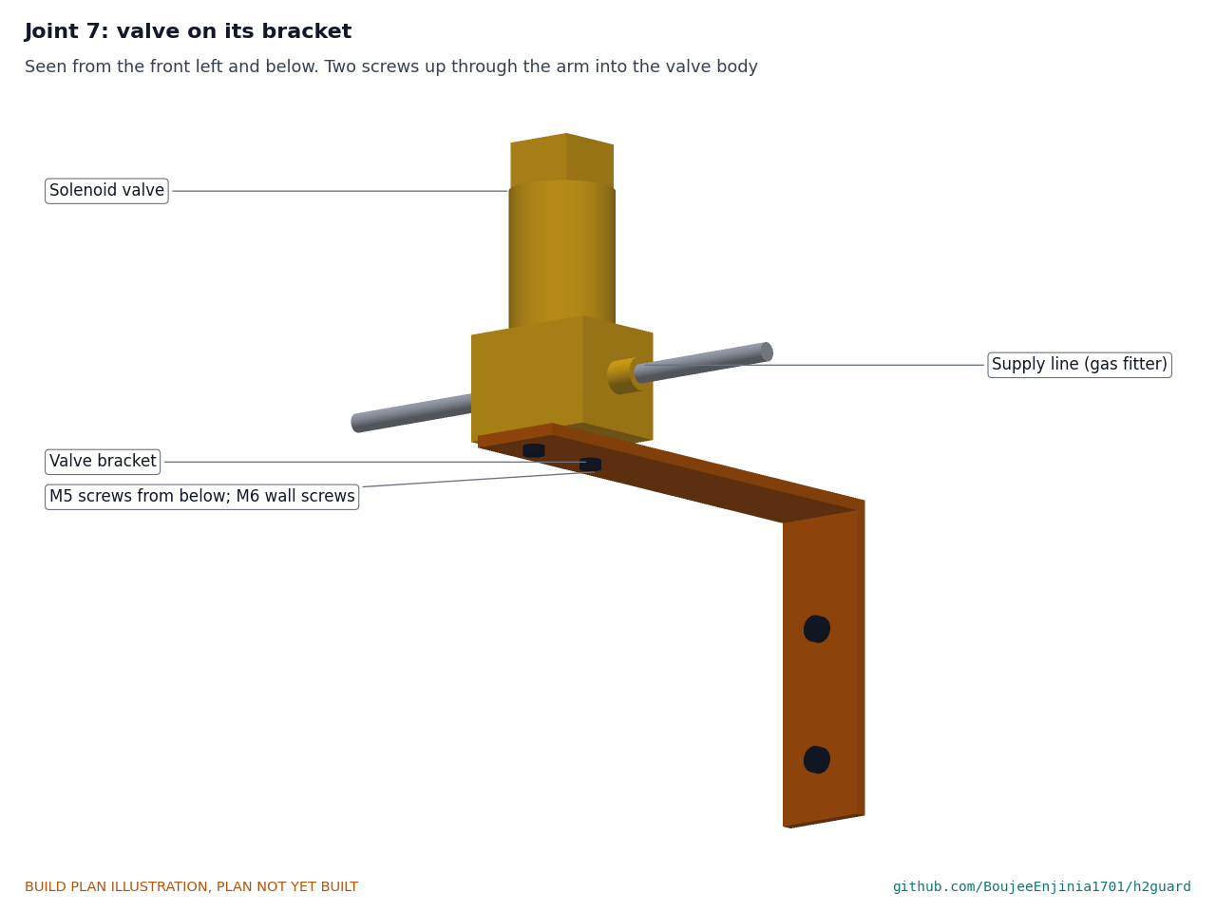
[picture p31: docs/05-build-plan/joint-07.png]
Figure 21. Joint 7: valve on its bracket


*Figure 21. Two M5 screws come up through the arm into the valve body; the gas fitter connects the supply to the valve's ports.*

The wall leg sits flat on the wall on two M6 screws with plugs; the arm is level, its top 1,277 mm above the floor. The valve sits on the arm, held by two M5 screws from below. The supply line connects to the valve's two ports, downstream of the regulator and flow restrictor.

**Check before moving on.** The arm is level and does not flex when you press on the valve.

### 3.11 Bought components

Buy to specification, not brand. Line numbers are those of the bill of materials.

- **Head box (line 1).** ABS or polycarbonate, 110 x 80 x 90 mm, lid on a 110 x 90 face, with an M16 cable gland. Drill as section 3.1.
- **Ceiling drop rod (line 17).** A 1/2 in malleable iron floor flange, a 1/2 in steel pipe nipple 89 mm long, two 1/2 in conduit locknuts, three M5 x 40 screws with ceiling plugs. Make up as section 3.4.
- **Catalytic and metal oxide sensors (lines 2 and 3).** A catalytic sensor reading 0 to 100 % LFL of hydrogen with a can about 20 mm across, and a metal oxide hydrogen sensor for about 30 to 3,000 ppm, each with its maker's datasheet and application note.
- **Arrestor discs (line 4).** Two sintered stainless steel discs 25 mm across and 2 mm thick, pores 50 µm or finer; two-part epoxy.
- **Controller box (line 5).** IP65 polycarbonate, 200 x 250 x 90 mm, clear lid on the front, four moulded bosses inside the back, corner fixing holes outside the seal; eight M16 cable glands.
- **Controller modules (line 6) and front panel parts (line 7).** As Table 2; a small display module, a key switch for a 19 mm hole, a push button for a 16 mm hole and three 5 mm lights in bezels.
- **24 V supply (line 8).** Certified plug-in or desktop unit, 24 V, 2.5 A (60 W).
- **Exhaust fan (line 9).** 150 mm mixed-flow EC duct fan, 24 V, about 450 m³/h in free air and 200 Pa at shut-off, speed input and tachometer output, body about 170 mm across with fixing holes in its inlet face; a 240 mm square inside grille; a 200 mm wall sleeve 150 mm long; a backdraft shutter for the 150 mm outlet; a weather hood with fixing tabs.
- **Make-up air grille (line 10).** Wall grille 300 x 160 mm with insect mesh and about 50 % free area.
- **Solenoid valve (line 11).** Two-way, normally closed, direct acting, 1/4 in, stainless steel body with FKM or PTFE seals and two tapped mounting holes underneath, 24 V DC coil of about 8 W, 0 to 10 bar. Its maker must state that it is suitable for hydrogen and give a seat leak rate. A low-cost brass valve may stand in only if its maker states both and it passes a seat leak proof test.
- **Pressure switch (line 18).** A low-range adjustable air pressure switch that can be set to about 3 Pa, with a changeover contact for 24 V DC and two barbs for 6 mm tube; about 0.5 m of 6 mm tube.
- **Dry-contact relay (line 19).** A relay module with a 24 V coil and a changeover contact rated 2 A at 30 V DC, and a 2-way screw terminal.
- **Oxygen sensor (line 20, only where inert gas cylinders share the room).** An electrochemical oxygen transmitter, 0 to 25 %, 24 V DC, 4 to 20 mA output, in an IP65 box with the cell facing down; 5 m of two-core cable.
- **Fan for a room used without close supervision (line 21).** In such a room, fit a 150 mm duct fan with its motor outside the air stream (a bifurcated fan) in place of line 9, of the same delivery. If it runs on mains, an electrician wires it through a certified contactor switched by the controller's fan relay.
- **Sounder and beacon (line 12).** 24 V DC, about 90 dB at 1 m, red flashing beacon.
- **Cable (line 13).** Four-core 0.5 mm² for the head, fan and beacon; two-core 0.75 mm² for the valve; two-core 0.5 mm² for the pressure switch and the dry-contact output; about 22 m in all, with surface conduit.
- **Fixings (line 14).** Four M3 x 22 mm female standoffs; M3 screws; 6 mm nylon standoffs; M2.5, M4, M5 and M6 screws; wall plugs; ferrules, heat-shrink and labels.
- **Test port, tube and fittings (line 15).** Bulkhead push-fit test port for 4 mm tube with a 12 mm thread and dust cap; about 3.5 m of 4 mm PTFE or nylon tube; an M5 straight push-in fitting; six saddle clips for the wall and two for the ceiling.
- **Bar and sheet (line 16).** 2 mm and 3 mm aluminium sheet, 30 x 30 x 3 mm angle and 40 x 5 mm flat bar for the made parts.

## 4. Putting it together

In each picture the parts already fitted are grey and the part being fitted is in colour, with an arrow showing the way it goes in. Steps 1 to 3, 5, 6 and 8 are bench work; the rest is done in the room. Step 15 applies only where inert gas cylinders share the room.

### Step 1: arrestor discs into the head

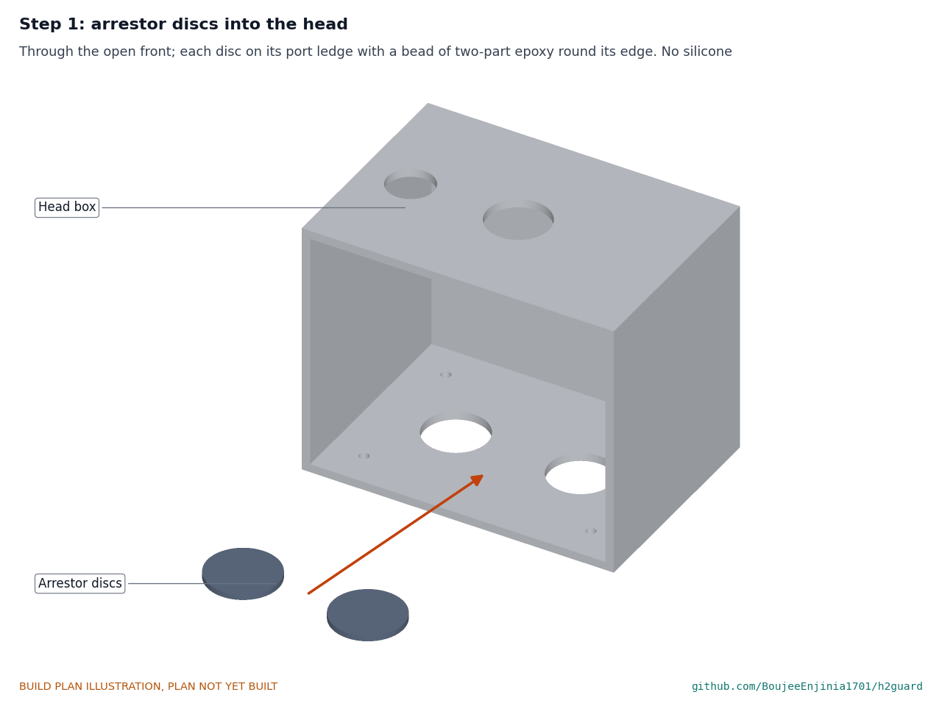
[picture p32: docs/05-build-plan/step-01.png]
Step 1


Through the open front, lay each disc on its port ledge and run a bead of two-part epoxy round its edge. Let it cure fully, with the box open to the air, before the sensors go in.

### Step 2: standoffs and bump test cup

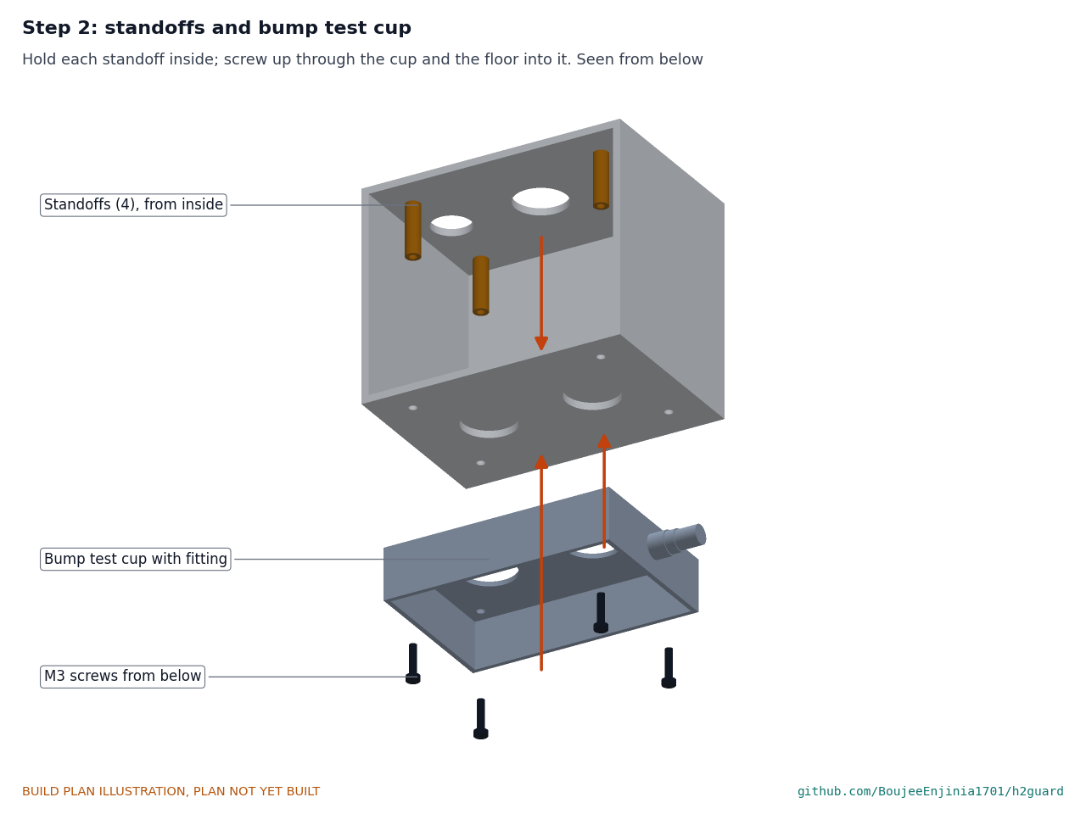
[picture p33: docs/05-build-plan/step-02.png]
Step 2


Hold each standoff on the inside of the floor and screw an M3 screw up through the cup's top plate and the floor into it. Check the cup's openings sit under the ports before tightening.

### Step 3: sensor board and cable gland

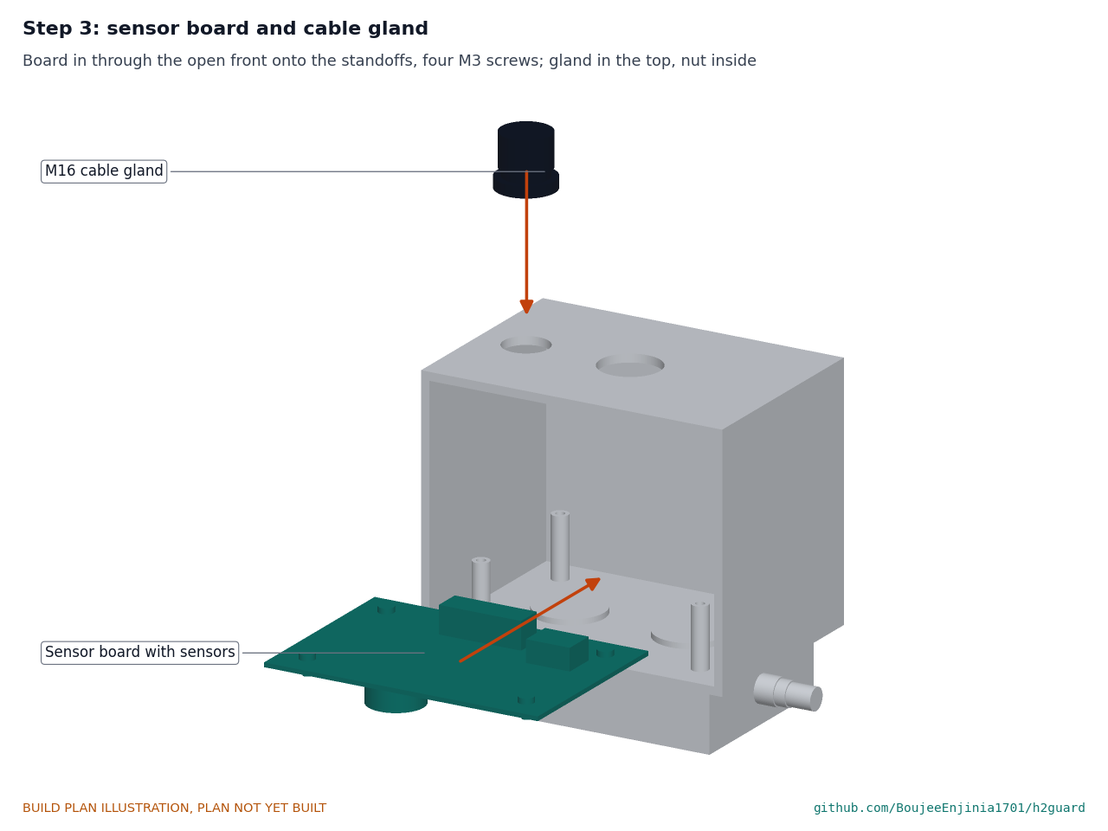
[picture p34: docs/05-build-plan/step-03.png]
Step 3


Slide the board in through the open front onto the standoffs and fit four M3 screws. Fit the cable gland in the top, nut inside.

### Step 4: detector head onto the ceiling drop rod

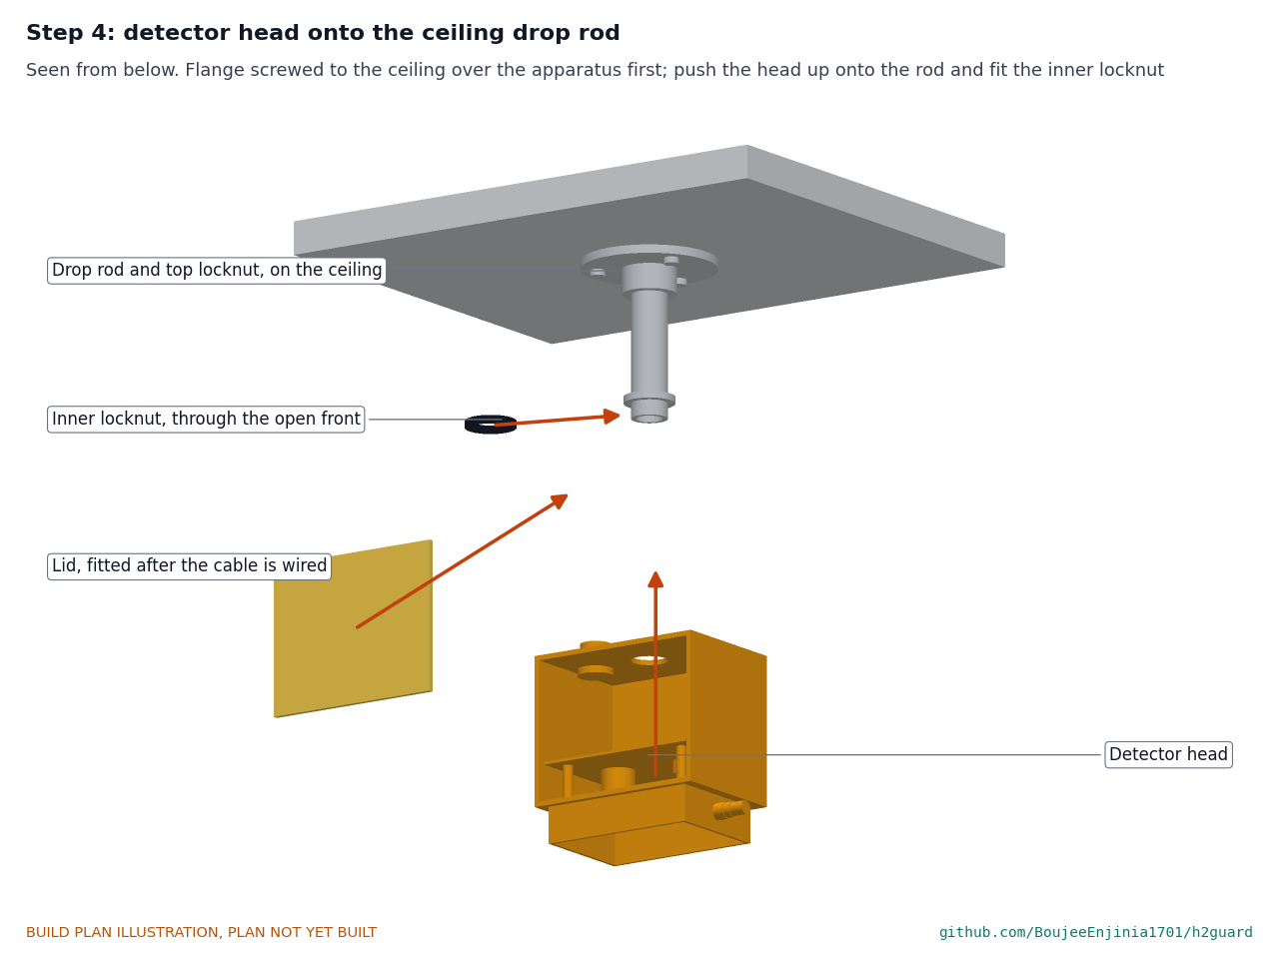
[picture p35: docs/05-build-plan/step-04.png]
Step 4


Find the apparatus centre on the ceiling with a plumb line and fix the flange there with the rod and its top locknut already on it (section 3.4), three M5 screws into ceiling plugs. Push the head up so the rod passes through the hole in its top and the top sits on the locknut, then fit the inner locknut through the open front and tighten it. The lid goes on after the cable is wired (step 17). **Hold point:** the sensor ports are 175 mm below the ceiling and the plumb line from the point midway between them lands on the apparatus centre.

### Step 5: glands and mounting plate into the controller box

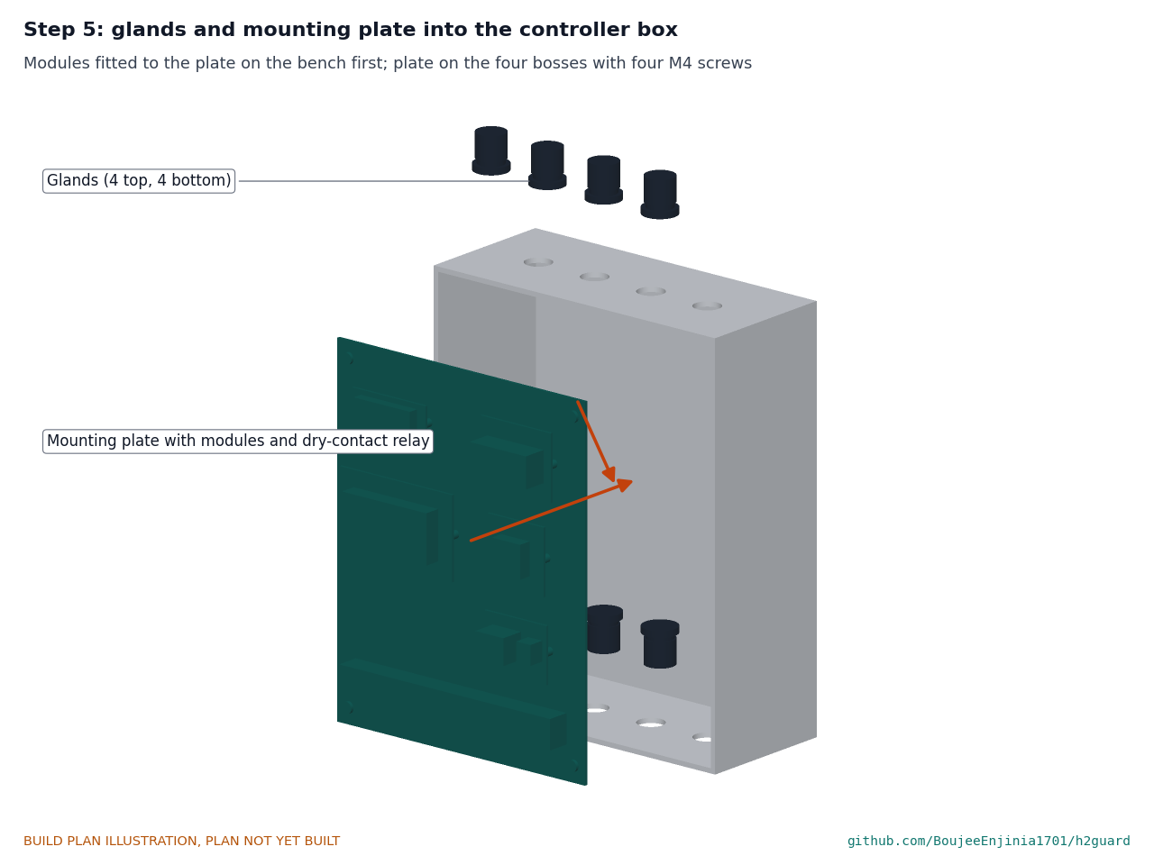
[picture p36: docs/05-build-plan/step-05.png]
Step 5


Fit the eight glands. With the modules and the dry-contact relay already on the plate and wired, set the plate on the bosses and fit four M4 self-tapping screws.

### Step 6: front panel parts into the lid

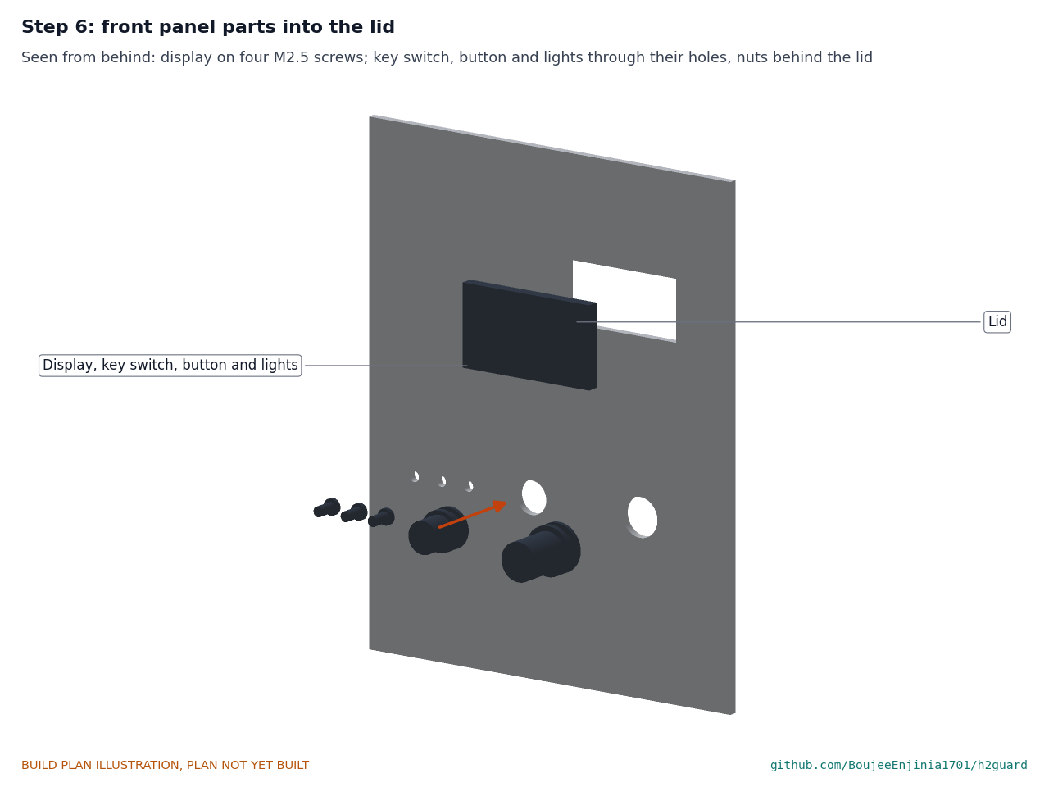
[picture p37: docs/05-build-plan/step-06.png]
Step 6


From behind the lid: the display on four M2.5 screws; the key switch, test button and lights through their holes, nuts behind the lid. Plug the ribbon cable into the display.

### Step 7: controller and test port bracket onto the wall

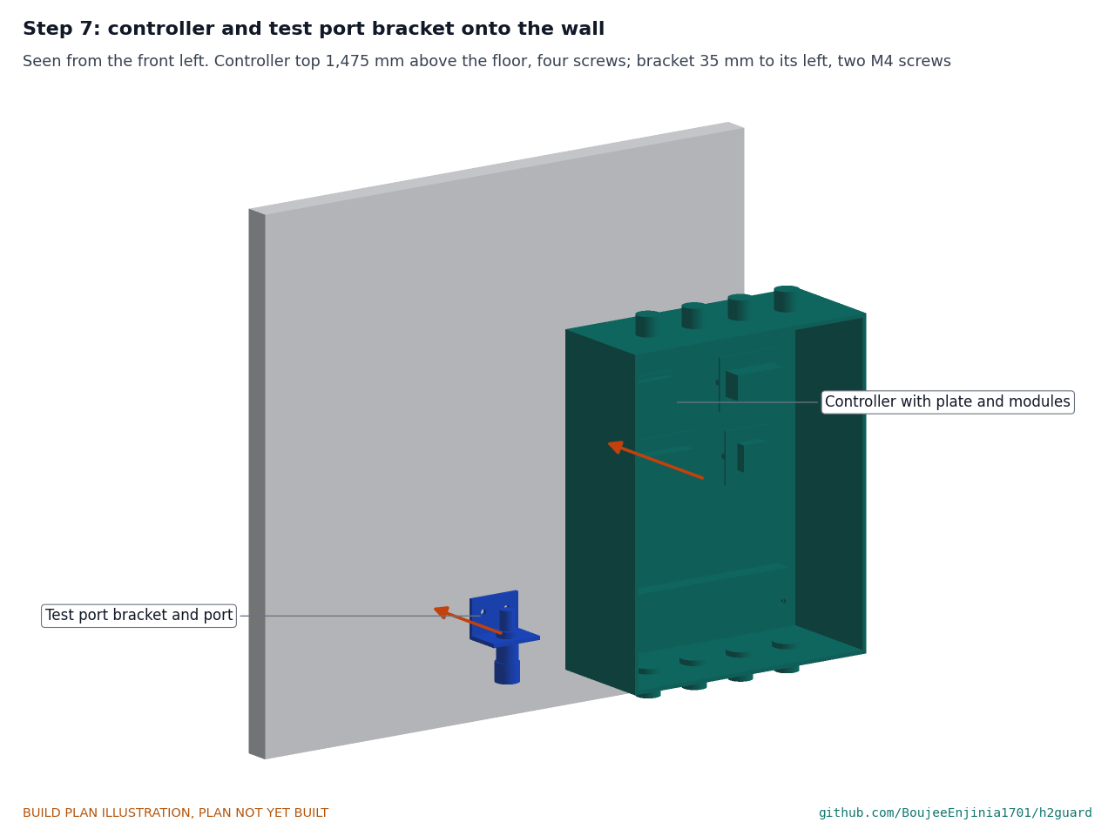
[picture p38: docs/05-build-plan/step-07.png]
Step 7


Controller box on the wall with its top 1,475 mm above the floor, four screws with plugs through the corner holes. Test port bracket 35 mm to its left, flat leg 1,250 mm up, two M4 screws with plugs. **Hold point:** the controller top is at least 1,000 mm below the ceiling.

### Step 8: fan onto the fan plate

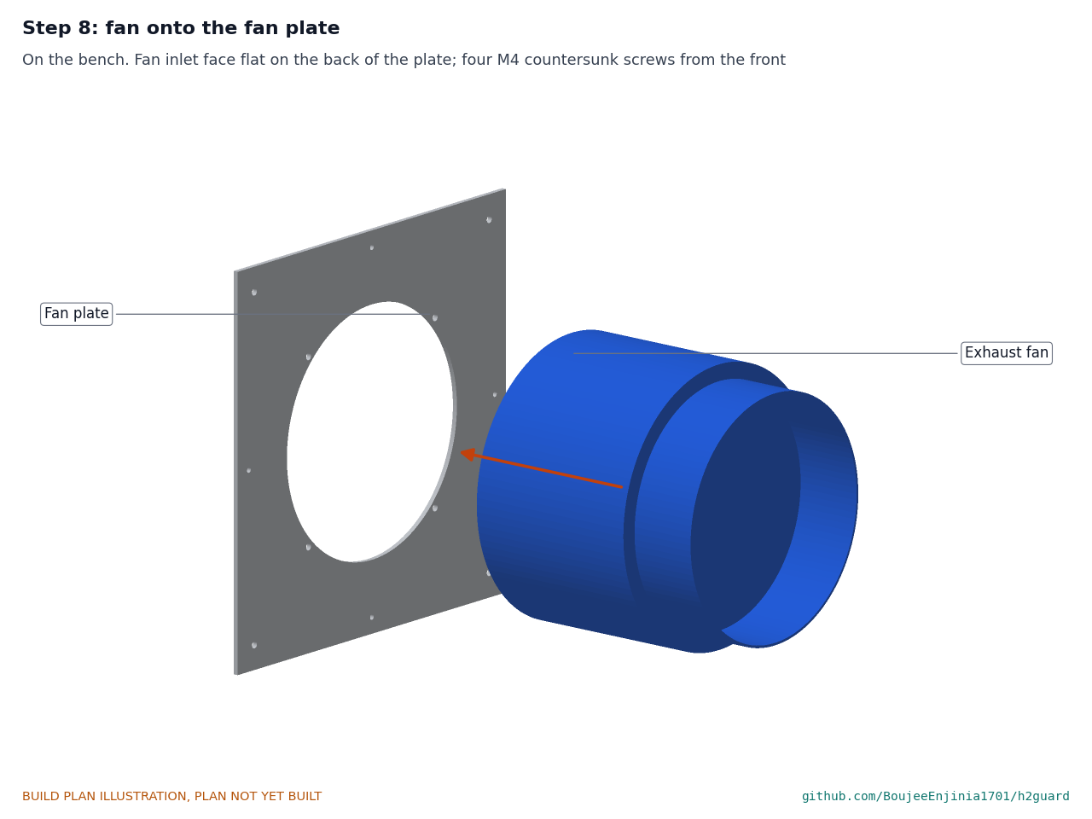
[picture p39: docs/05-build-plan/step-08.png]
Step 8


On the bench. The fan's inlet face flat on the back of the plate, four M4 countersunk screws from the front.

### Step 9: sleeve and fan into the wall

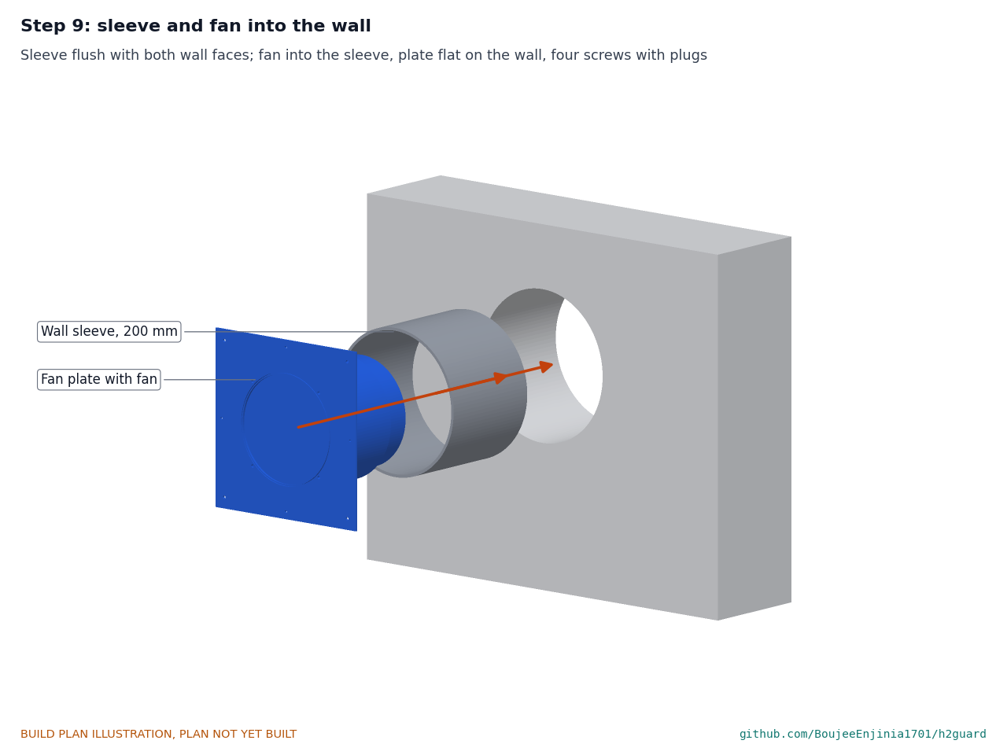
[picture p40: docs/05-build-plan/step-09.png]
Step 9


The builder's 206 mm opening is centred 2,300 mm above the floor. Push the 200 mm sleeve in flush with both wall faces. Slide the fan body into the sleeve and fix the plate flat on the wall with four countersunk screws and plugs.

### Step 10: grille, shutter and weather hood

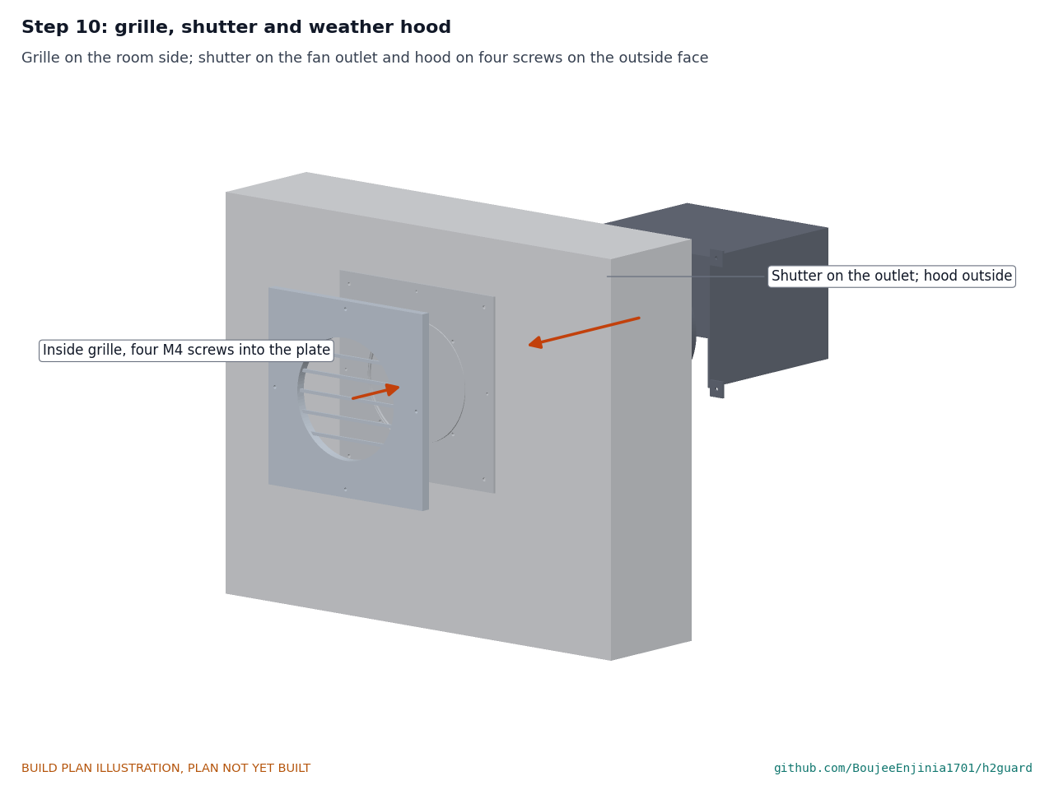
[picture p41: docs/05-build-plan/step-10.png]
Step 10


Inside grille onto the plate with four M4 screws. Outside, push the backdraft shutter onto the fan's outlet spigot, flap hanging closed, then fix the weather hood over it, open side down, with four screws and plugs.

### Step 11: pressure switch and its tube

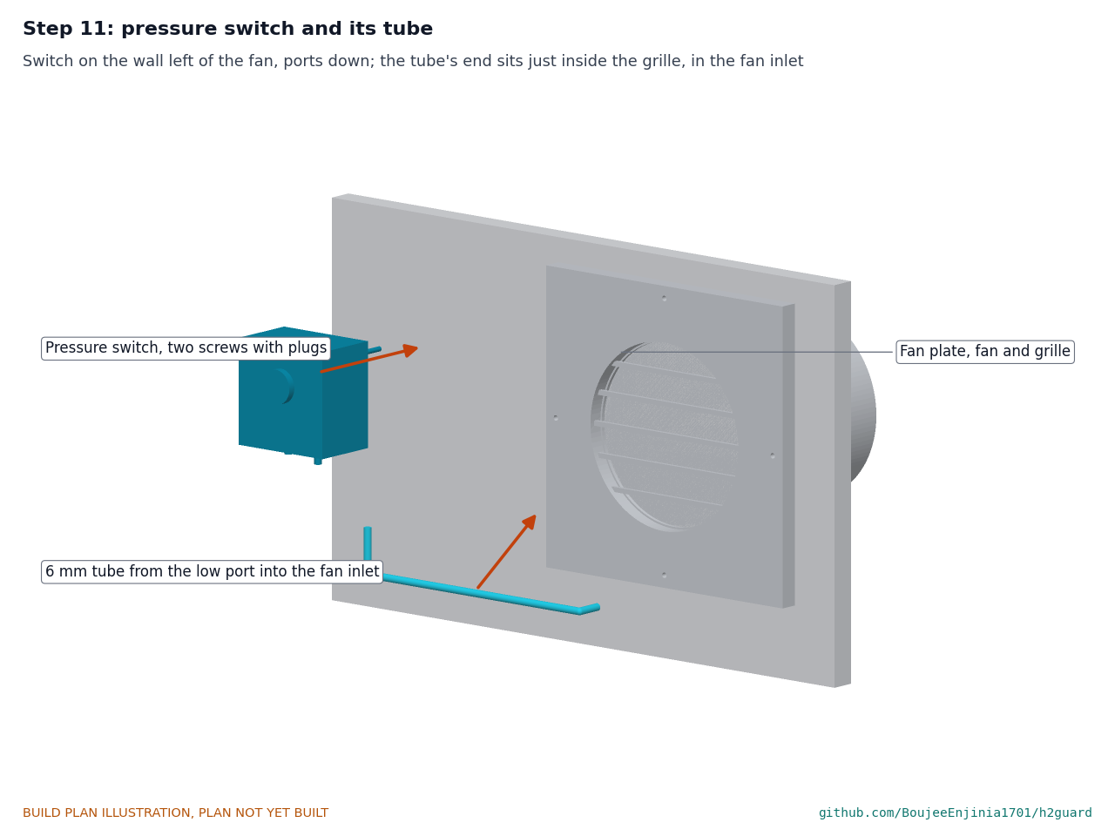
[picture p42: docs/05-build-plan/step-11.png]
Step 11


Switch on the wall left of the fan plate, ports down, two screws with plugs. Push the 6 mm tube onto the low port, run it down and across in front of the grille, and push its end through the grille opening, 62 mm below the fan's centre, until it sits just inside the grille. Leave the high port open. Set the switch to about 3 Pa.

### Step 12: make-up air grille

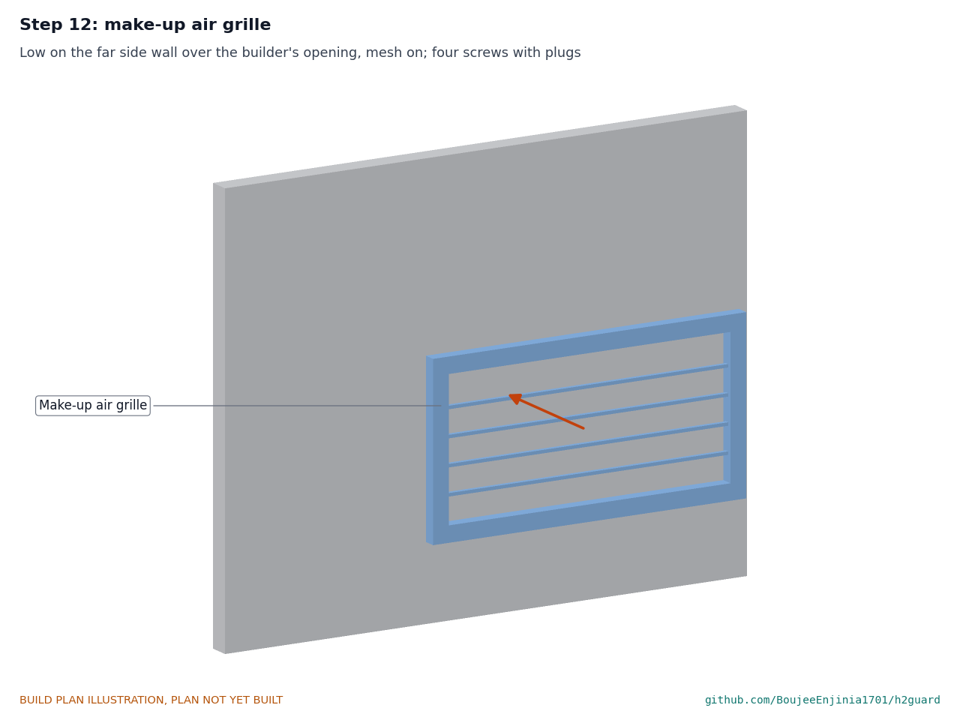
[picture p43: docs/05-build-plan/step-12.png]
Step 12


Low on the side wall opposite the fan, over the builder's opening, centred 200 mm above the floor, mesh fitted; four screws with plugs.

### Step 13: valve bracket and valve

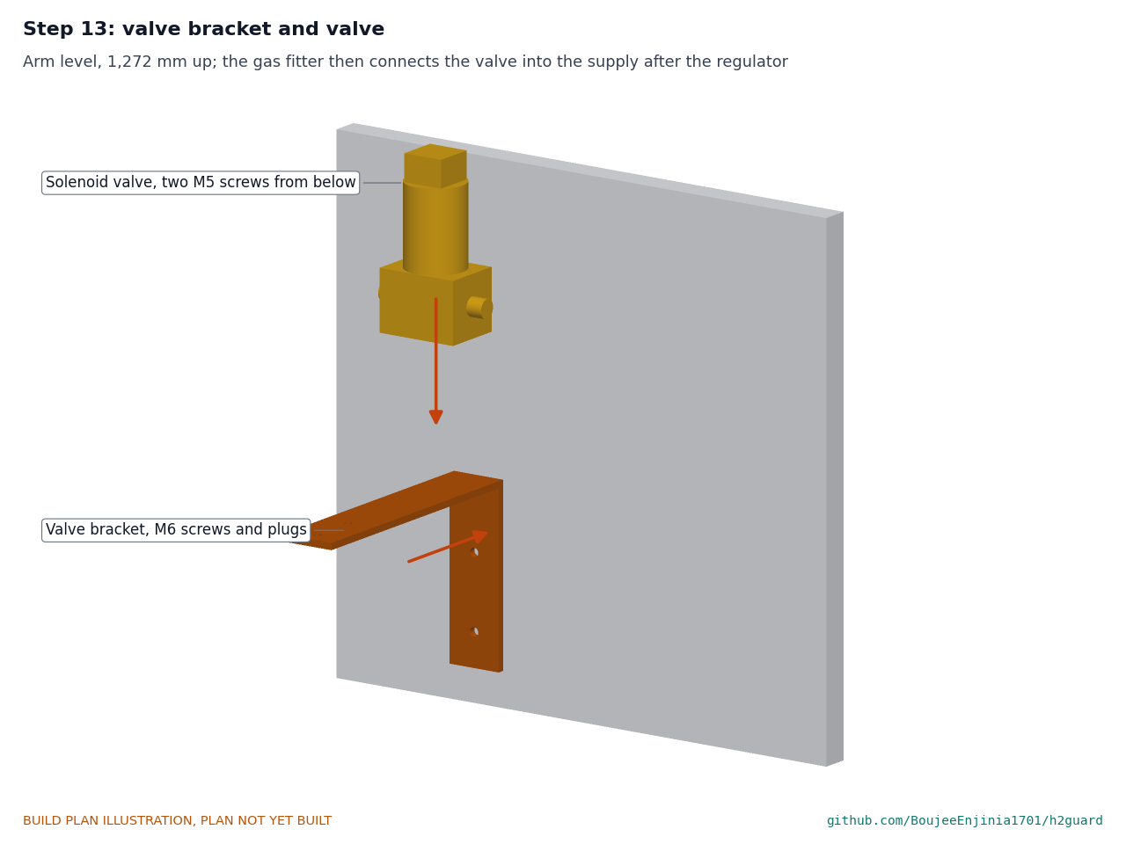
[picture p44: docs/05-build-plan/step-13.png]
Step 13


Bracket on the wall with the arm level and its top 1,277 mm above the floor, two M6 screws with plugs. Valve on the arm, two M5 screws from below. **Hold point:** the gas fitter connects the valve into the supply after the regulator and flow restrictor, and leak tests the joints with inert gas; no hydrogen is connected yet.

### Step 14: sounder, beacon and power supply

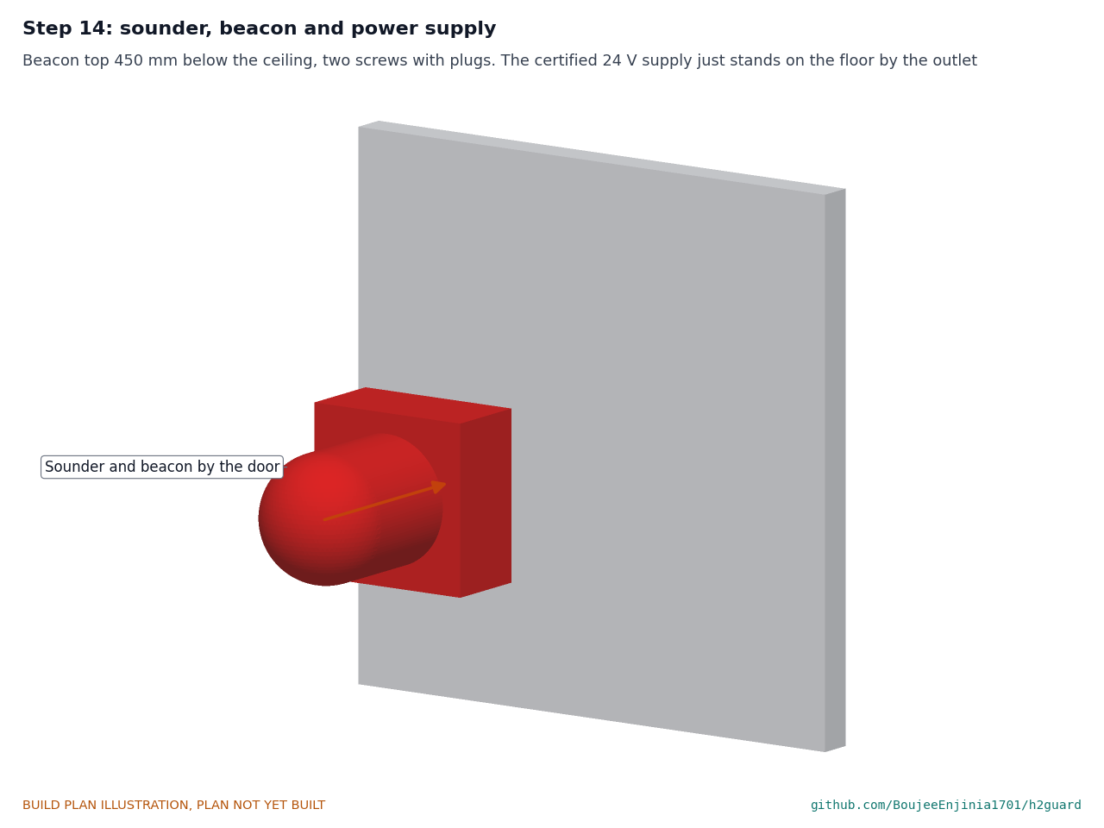
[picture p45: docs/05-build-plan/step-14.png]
Step 14


Sounder and beacon by the door with its top 450 mm below the ceiling, two screws with plugs. Stand the 24 V supply on the floor by the outlet; do not plug it in yet.

### Step 15: oxygen sensor (only where inert gas cylinders share the room)

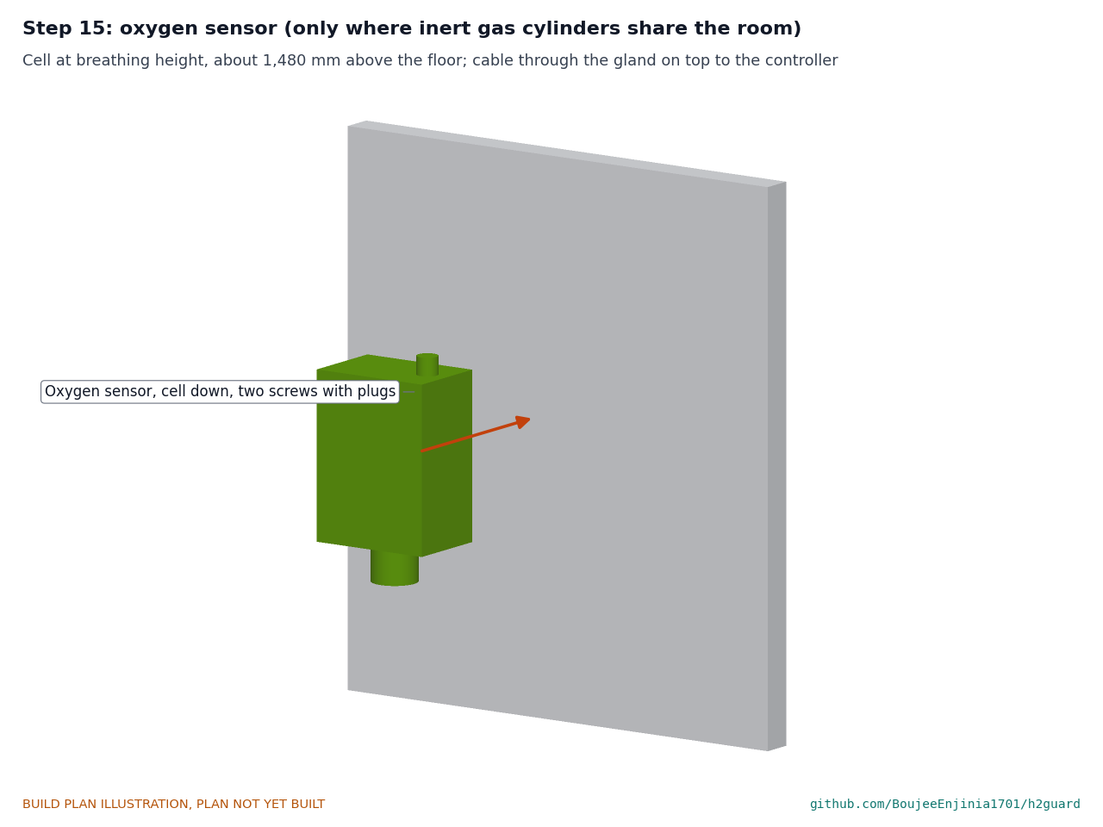
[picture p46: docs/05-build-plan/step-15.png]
Step 15


On the back wall, 450 mm left of the controller, with the cell facing down about 1,480 mm above the floor, at breathing height; two screws with plugs. Its cable runs from the gland on top down the wall to the left-hand bottom gland of the controller.

### Step 16: bump test tube and clips

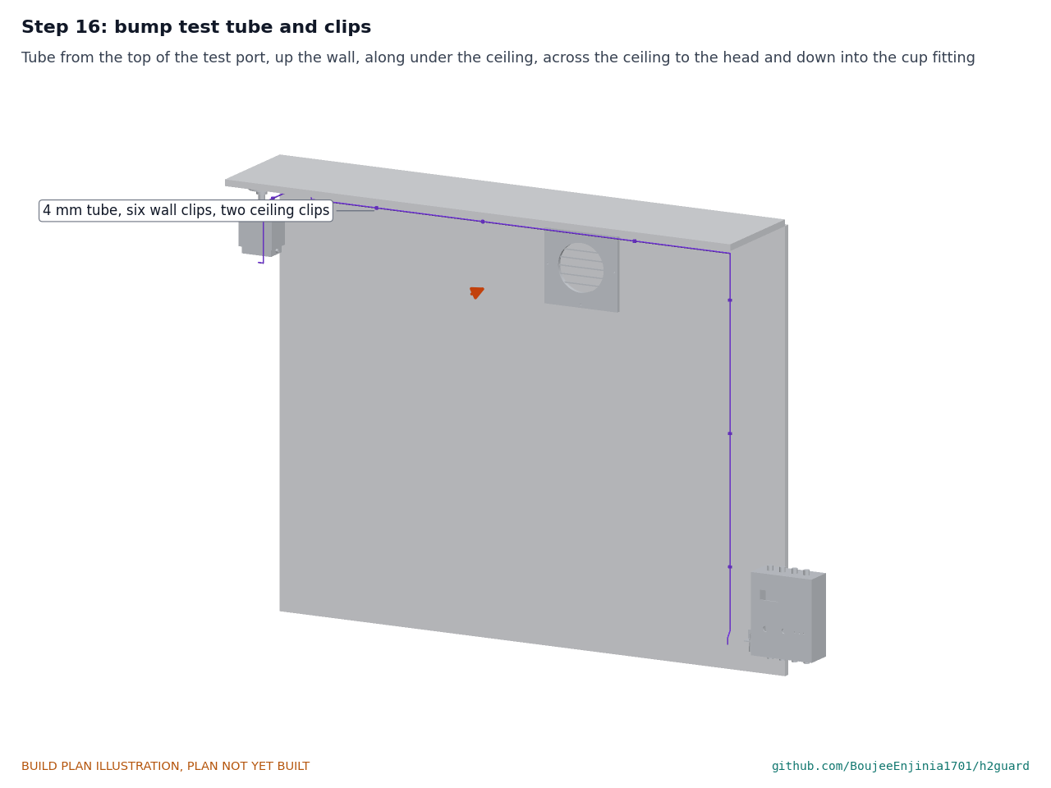
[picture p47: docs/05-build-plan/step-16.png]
Step 16


Push the 4 mm tube into the top of the test port, run it up the wall beside the controller and along the wall 60 mm under the ceiling, then up into the corner and out across the ceiling to the head, and down beside the head into the cup's fitting. Six saddle clips hold it on the wall and two on the ceiling; keep it clear of the fan grille, the drop rod and the cables.

### Step 17: wire up and close the lids

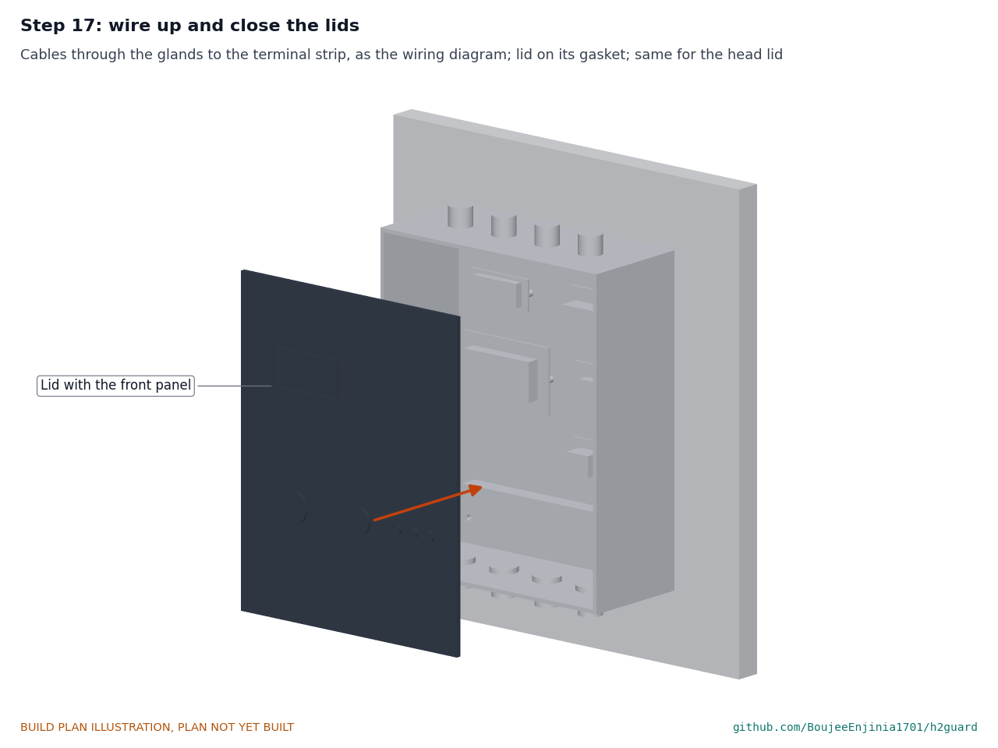
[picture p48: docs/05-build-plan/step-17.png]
Step 17


Run the cables in surface conduit and through the glands to the terminal strip and the head's terminal, as Figure 13. Close the controller lid and the head lid on their gaskets. **Hold point:** safety stops S1 and S2 in section 6.

## 5. First checks

These are the checks a TRL 4 test report would record; this plan only lists them. Requirement numbers are those of HGD-REQ-001.

*Table 3. First checks.*

| Check | Requirement | How | Pass when |
| --- | --- | --- | --- |
| Mounting heights | R1, R15 | Tape measure from the ceiling | Head ports 175 mm below the ceiling, give or take 10 mm; controller top at least 1,000 mm below |
| Head over the leak point | R1 | Plumb line from the point midway between the head's ports | Lands on the apparatus centre, within 20 mm |
| Power draw | R11 | Meter in the 24 V lead, normal state and with the test button held | Under 60 W at the peak (48.7 W estimated) |
| Fail-safe on power loss | R5 | Unplug the 24 V lead with the valve open (inert gas in the line) | The valve closes; flow stops |
| Hardware trip | R6 | With the microcontroller held in reset, feed the trip board's input a voltage equal to 25 % LFL | The series relay opens and the valve closes; only the key resets it |
| Sensor fault | R5 | Open and then short the catalytic sensor input | Valve closed within 2 s; fault shown |
| Fan stop | R5, R7 | Hold the fan still (supply off at the fan) | Valve closed within 2 s of the 10 s tachometer timeout |
| Airflow proving | R5, R7 | With the fan running, cover the outside of the weather hood with a board | The pressure switch opens and the valve closes within 2 s of its 10 s timeout |
| Dry-contact output | R3, R5 | Meter across the output terminal; press TEST, then unplug the 24 V lead | The contact opens each time |
| Oxygen sensor (if fitted) | Precis, decision 4 | Read it in fresh air | About 20.9 % oxygen |
| Ventilation | R7 | Vane anemometer across the inside grille at continuous and boost speed | At least 150 m³/h continuous and 300 m³/h on boost |
| Alarm | R10 | Sound meter at 1 m from the sounder | 85 dB(A) or more; beacon visible from the door |
| Bump test | R12 | Certified 1 % hydrogen in air at 1 L/min into the test port (after stop S4) | The catalytic reading rises and the system trips within 120 s |
| Self-test | R12 | Press TEST | Sounder, beacon, fan boost and valve close all run |

## 6. Safety stops

Stop at each point. Carry on only when everything listed is true.

- **S1. Before the 24 V supply is plugged in.** The supply is a certified unit with an undamaged lead. With it unplugged, no 24 V terminal reads short to 0 V. The valve coil wiring passes through the series relay and the driver switch. Every gland is tight and every lid closed.
- **S2. Before the sensors are powered.** The epoxy round the discs has cured for its full time with the head open; no silicone, flux cleaner or solvent has been used in or near the head.
- **S3. Before any gas reaches the valve.** A competent gas fitter has connected the valve after the regulator and flow restrictor and leak tested every joint with inert gas. The fault checks of section 5 (power loss, hardware trip, sensor fault, fan stop, airflow proving) all close the valve.
- **S4. Before the first bump test.** The test gas is a certified mixture of no more than 1 % hydrogen in air, in a disposable cylinder with its own regulator set to about 1 L/min. The fan is running. Someone stands by the controller with the key. Expect the system to trip; reset only when the reading is below 10 % LFL.
- **S5. Before hydrogen from the room's supply is turned on.** The hydrogen inventory in the room is within the 300 L limit (1 % of room volume at atmospheric pressure), or a flow restrictor limits a failure to 5 L/min. The bump test has passed that day. The room has a second, certified means of protection wherever codes or insurers require one. The head hangs on its drop rod with its ports over the apparatus (step 4). The pressure switch has proved that it closes the valve when the airflow stops. The valve is the hydrogen-rated valve, or a brass valve with its maker's hydrogen and seat leak ratings that has passed a seat leak proof test. If inert gas cylinders share the room, the oxygen sensor is fitted and reads about 20.9 % in fresh air. The set points are the stricter of the defaults, the national code, ISO 26142 and the host institution's safety office rules.
- **S6. Every teaching session.** Bump test before use and after any exposure to silicone or solvent vapour; check that the valve closes on TEST. A leaking valve seat is not detected by the system.

## 7. Tools, skills and workspace

**Tools.** Bench drill or a drill in a stand; drills 2.5 to 12 mm; step drill to 20 mm; 152 mm hole saw (or a jigsaw with a metal blade); countersink; M4 and M5 taps and tap drills; hacksaw; bench vice with soft jaws and a radiused jaw for bending; flat and half-round files; deburring tool; scriber, square, steel rule and calipers; feeler gauges; 3D printer that prints PETG with a bed of at least 100 x 70 mm; soldering iron; ferrule crimper and wire strippers; multimeter; screwdrivers and nut drivers; masonry drill and wall plugs for the room; pipe wrench for the drop rod; spirit level; tape measure and plumb line. The fan and make-up air openings need a 206 mm core drill and a builder.

**Skills.** Basic metalwork (marking out, drilling, filing, tapping, bending flat bar), through-hole soldering, crimping, and reading a sensor datasheet and application note. All circuits are 24 V DC or lower; mains appears only inside the certified supply. The gas connection must be made and leak tested by a competent gas fitter.

**Workspace.** A bench about 1.2 x 0.6 m with the metalwork kept apart from the electronics; a ventilated place for the printer; a step ladder with a second person for work at the ceiling.

**Personal protective equipment.** Safety glasses for drilling, cutting and soldering; gloves for cut aluminium; dust mask and hearing protection when drilling masonry; no gloves near a turning drill.

## 8. Where the numbers come from

- Model and constructability checks: `cad/src/model.py` (`python cad/src/model.py --check`, 182 checks); STEP and STL exports in `cad/step/` and `cad/stl/`.
- Pictures: `cad/src/build_plan_media.py`, using `.kit/build_views.py`; written to `docs/05-build-plan/` and `cad/drawings/HGD-DWG-101` to `HGD-DWG-110`.
- General arrangement: `cad/drawings/HGD-DWG-001.pdf`, Rev P5.
- Calculations: `docs/04-calcs/01-sizing.md` (HGD-CAL-001 v0.4) and `docs/04-calcs/sizing.py`; head over the plume [E7], arrestor lag [F1], fan delivery [G3], pressure switch [G6], power [H2], bump test [J1], installation [M1], cost [N1].
- Bill of materials: `bom/bom.csv`.
- Decisions: `docs/decisions/0003-design-for-construction.md` (HGD-DDR-003), with HGD-DDR-001 and HGD-DDR-002.
- Requirements: `docs/03-requirements.md` (HGD-REQ-001 v0.7).

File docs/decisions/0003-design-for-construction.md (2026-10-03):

---
doc_id: HGD-DDR-003
title: H2Guard design for construction
project: H2Guard
doc_type: Design decision record
version: "0.3"
status: Draft
date: '2026-10-02'
author: Amish Chadha
license: CERN-OHL-S-2.0
revisions:
- version: "0.1"
  date: '2026-10-01'
  author: Amish Chadha
  change: Changes that make the concept physically buildable, with the reason for each; made under Amish's 2026-09-30 instruction to make the design physically buildable; open for his review
- version: "0.2"
  date: '2026-10-02'
  author: Amish Chadha
  change: Accepted by Amish; A1 decided as a ceiling drop rod (changed recommendation) and A2 accepted for the supervised prototype only
- version: "0.3"
  date: '2026-10-02'
  author: Amish Chadha
  change: Consequences updated after the approved follow-ups were carried into the model, drawings, build plan, calculations and appearance model
---

# 0003: Design for construction

- **Date:** 2026-10-01
- **Status:** accepted. Amish, 2026-10-02: "i approve your recommendations for all 555 open decisions." This covers every change in Table 1 and the recommendations for A1 and A2 in Table 3 as written for the register on 2026-10-01 (HGD-DEC-001): A1 was changed from the wall mounting proposed here to a ceiling drop rod, and A2 was sharpened. Every change in Table 1 was made under Amish's 2026-09-30 instruction to make the design physically buildable. Nothing in Table 1 changes what H2Guard does, its pitch or its safety case. The cost is reported against the value-engineering target (Table 2) and needs no decision.

## Context

On 2026-09-30 Amish asked for every repo to have an illustrated prototype build plan and wrote: "If you are realising that the design cannot be built as per concept - fix the design assumptions to match and be physically feasible as you draw the illustrations." The TRL 3 model (`cad/src/model.py`) showed what H2Guard does and where each part goes in the room, but several parts were shapes that could not be made, fitted or held as drawn. Checking the model with build123d (intersections, distances and clearances between parts) found the problems P1 to P11 below.

The changes keep what the system does: the same room, the same detector head size and mounting height with the ports 175 mm below the ceiling, the same sensors, arrestor discs, sensor gap, bump test cup volume, controller, fan air path, valve, sounder and beacon, power supply and set points. `cad/src/model.py` now builds each part a maker handles, with its fixings, and runs 127 constructability checks (`python cad/src/model.py --check`): parts that must touch do touch without overlapping, parts that must stay apart keep the stated clearance, no two parts overlap, and every part bears on the wall, floor or a neighbour. All 127 pass.

## Decision

*Table 1. Changes made to the model, the BOM and the calculations.*

| # | Problem in the concept | Change made | Why this way |
| --- | --- | --- | --- |
| P1 | The bump test cup's 2 mm top plate covered both sensor ports completely (2,118 mm³ of plastic across the openings), so no gas could reach the sensors. | Two 22 mm openings in the cup's top plate, in line with the ports. | Restores the gas path. The cup volume used in the calculations (114 mL) already assumed a top plate, so it is unchanged. |
| P2 | The 25 mm arrestor discs sat in 26 mm ports with nothing to hold them: they would drop through. | Ports drilled 22 mm; each disc rests on the 1.5 mm ledge this leaves on the inside of the floor and is bonded round its edge with a bead of two-part epoxy (never silicone, which poisons catalytic sensors). | The disc stays where the calculations put it (on the floor, 2.2 mm below the sensor can), so the 1.5 s arrestor lag [F1] is unchanged, and the bonded edge stops gas bypassing the disc. |
| P3 | A wall plate fused to the back of the head cut 2.5 mm into the box's inside (21,840 mm³ of overlap), and the head had no fixing to the wall. | Wall plate removed. The head box is a stock box with its lid on the room-side face; two M4 screws with wall plugs go through its back wall from inside. | Uses what a stock box offers; the head's size and position are unchanged. |
| P4 | The sensor carrier board and the cup had no fixing. | Four 22 mm M3 female standoffs on the floor of the head. Four M3 screws come up through the cup's top plate and the head floor into the standoffs; the board sits on the standoffs on four more M3 screws. | One set of standoffs holds both the cup and the board, and the standoff length sets the 22 mm floor-to-board gap that gives the 2.2 mm sensor gap. |
| P5 | The cup's gas nozzle was a solid stub with no way to connect the 4 mm tube. | A printed boss on the cup's side, tapped M5, with a straight push-in fitting for 4 mm tube. | A standard pneumatic fitting; the tube pushes in and pulls out with the collet. |
| P6 | The controller board floated 4.5 mm off the box's back wall with no fixing, and the modules cut 0.5 mm into it. | A 2 mm aluminium mounting plate on the box's four moulded bosses, four M4 self-tapping screws; each module on M3 screws and 6 mm nylon standoffs. | Stock IP65 boxes have these bosses; the modules can be bought and fitted without a laid-out circuit board, which is TRL 4 work. |
| P7 | The front panel floated 4 mm in front of an open-fronted box. | The panel is the box's own lid, cut for the display window, key switch, test button and three lights; each part is held through its hole by its nut or screws. | The lid closes on the box's gasket with the panel parts in it. |
| P8 | The controller had no cable entries and no wall fixing. | Five M16 cable glands (four in the top for the head, fan, valve and beacon cables, one in the bottom for the supply lead) and four screws through the box's corner fixing holes. | Keeps the box sealed; cables arrive from the trunking above and the supply from the floor below. |
| P9 | The bump test port overlapped a solid block that stood in for its bracket, and the tube did not start at the port. | A 40 mm length of 30 x 30 x 3 mm aluminium angle on the wall 35 mm left of the controller, with the bulkhead port pointing down through its flat leg (cap underneath, push-fit on top); the tube rises from the port and runs on the wall in seven saddle clips. | Span gas is connected from below at chest height, and the tube follows the wall to the head as in the concept (2.72 m instead of 2.69 m [J1]). |
| P10 | The fan was drawn as a 146 mm motor floating inside the 150 mm sleeve with no support, although the fan specified has a body about 170 mm across; the sleeve also cut into the inside grille. | A 200 mm wall sleeve takes the 170 mm fan body. A 3 mm aluminium fan plate on the inside wall face holds the fan by four screws into its inlet face; the inside grille screws to the plate; the backdraft shutter fits on the fan's outlet spigot and the weather hood screws to the outside wall by four tabs. | The air still passes through the fan's 150 mm spigots, so the duct losses and the 347 m³/h boost [G3] are unchanged. The wall opening grows from about 160 to 206 mm; it is builder's work, already outside R13. |
| P11 | The solenoid valve hung in mid-air 148 mm from the wall, and the supply line passed straight through its body (4,222 mm³ of overlap). | A bracket bent from 40 x 5 mm aluminium flat bar: a 132 mm leg on the wall on two M6 screws with plugs, and a 200 mm arm under the valve, which is held by two M5 screws into the tapped holes under its body. The supply line now ends at the valve's two ports. | Supports the valve independently of the gas line, so the gas fitter's joints carry no load. |

*Table 2. Knock-on changes.*

| Item | Change | Reason |
| --- | --- | --- |
| BOM | Lines 1, 2, 4, 5, 6, 7, 9, 11, 14 and 15 re-specified; line 9 (larger sleeve) +USD 5, line 14 (standoffs, screws, epoxy) +USD 4, line 15 (push-in fitting, clips) +USD 2; new line 16, made brackets and plates, USD 14. | Parts added for construction. |
| Cost | Value-engineering target USD 265 (`budget_usd`, unchanged). Estimated cost of the constructable design USD 289, USD 24 over the target [N1]. R14 is reported against the target. | The concept left out brackets, plates and fixings. |
| Installation | 255 min (4.2 h) with the wall openings as builder's work, 15 min over R13's 4 h (it was 5 min over) [M1]; R13 stays at risk. | Ten more minutes to fix the valve bracket. |
| Bump test | Tube 2.72 m, 13.3 mL; the reading still settles in about 67 s [J1]. | Tube route follows the bracket and clips. |
| Calculation note | HGD-CAL-001 v0.3; HGD-REQ-001 v0.5 (R13, R14 status). No other figure changed. | Follows the model. |
| Drawings and media | HGD-DWG-001 Rev P4; making sketches HGD-DWG-101 to 109 added; concept blueprint HGD-DWG-010 Rev P4; concept media and STEP and STL files regenerated. | Follows the model. |

*Table 3. Proposed for Amish; decided on 2026-10-02 as shown under each recommendation.*

| # | Question | Options | Recommendation |
| --- | --- | --- | --- |
| A1 | The head is mounted on the back wall above the bench, so its ports sit 110 mm horizontally from the back edge of the apparatus and 260 mm from its centre, against a plume radius of about 141 mm at the ports [E7]. This touches the head placement rule, which is part of the safety case. | (a) keep the wall mounting and set the offset limit by test at TRL 4, as decided; (b) hang the head from the ceiling directly over the apparatus on a drop rod. | (a) for the prototype, since the offset limit is already a TRL 4 test; revisit if the test shows the offset matters. Changed in the recommendation to Amish and decided on 2026-10-02: (b), the head hangs from the ceiling on a drop rod directly over the apparatus; wall mounting only if the TRL 4 plume test shows a trip at the wall position. At the wall position the design leak would only warn, and the valve would wait for the 5 min escalation with about 28 L released. |
| A2 | The fan motor now sits inside the wall sleeve rather than partly in the room. The safety case already notes the motor is in the exhaust stream and not rated for hazardous areas. | (a) accept; (b) specify a fan with the motor outside the air stream (a belt or external-rotor design). | (a); no change to the ignition-source argument, which relies on continuous running. Decided on 2026-10-02: (a) for the supervised teaching prototype; (b) for any room used without close supervision, since the argument rests on supervision. |

## Consequences

- `design_state: constructable` in `project.yaml`. The build plan HGD-BLD-001 shows every component and step in pictures generated from the model (`cad/src/build_plan_media.py`), and the design decisions register HGD-DEC-001 indexes the decisions.
- With A1 decided as (b), the model, drawings, build plan and calculation E7 were updated to the ceiling drop rod on 2026-10-02 (`docs/REVIEW.md`, approved follow-ups carried out).
- Requirement status after the decisions of 2026-10-02: 1 not met on estimate (R13), 2 at risk (R4, R7), 1 not verifiable at TRL 3 (R1), 6 met on paper, 4 met by design, and R14 over the value-engineering target by USD 146 (HGD-CAL-001 v0.4).
- The appearance model `cad/src/product_model.py` was updated to the constructable design on 2026-10-02 and its render scenes exported; the photoreal renders, `media/card.png` and `media/social-preview.png` are to be regenerated from them on Amish's Mac, where Blender is.
- The box, fan and valve are chosen at TRL 4. The head box lid face, the controller box bosses and corner holes, the fan's inlet-face fixing holes and the valve's tapped mounting holes must be checked then, and the made parts drilled to suit.

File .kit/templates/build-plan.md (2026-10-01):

---
doc_id: PRJ-BLD-001
title: Project prototype build plan
project: Project name
doc_type: Build plan
version: "0.1"
status: Draft
date: YYYY-MM-DD
author: Amish Chadha
license: CERN-OHL-S-2.0
revisions:
  - version: "0.1"
    date: YYYY-MM-DD
    author: Amish Chadha
    change: First build plan; design made constructable
---

# Project prototype build plan

**Plan, not yet built.** How to build the first proof-of-concept prototype, component by component. Building and testing to it is TRL 4 work. Decisions still to be made are kept in the design decisions register (`docs/06-design-decisions.md`), not here.

## 1. What you are building

Every component, pulled apart and numbered in build order

One short paragraph: what the prototype is, how many components, which are made and which are bought, and the main ways they are made.

## 2. What changed to make it buildable

| Component | The concept had | The buildable design has | Why |
| --- | --- | --- | --- |

## 3. Making the components

### 3.1 Component name

Making sketch

**What it is and what it is made from.**

**How to make it.**

1. Mark out ...
2. Cut ...

**How it fits the parts next to it.**

Close-up of the joint

**Check before moving on.**

## 4. Putting it together

### Step 1: ...

Step 1

## 5. First checks

| Check | Requirement | How | Pass when |
| --- | --- | --- | --- |

## 6. Safety stops

## 7. Tools, skills and workspace

## 8. Where the numbers come from

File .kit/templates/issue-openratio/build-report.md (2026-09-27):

---
name: Build report
about: Tell us what happened when you built, printed or tested part of this design
title: "Build report: "
labels: build-report
---

This is a research and educational prototype, not a medical device. It is a TRL 3 concept and is not released for fabrication. If you build any part of it, you do so at your own risk. Reports help everyone.

**What you built** (part, sub-assembly or test)

**Materials, tools and settings**

**What worked**

**What did not work, with photos or measurements if you have them**

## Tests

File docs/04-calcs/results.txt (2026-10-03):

[A1] LFL 4.0 % vol; warning 10 % LFL = 0.40 % vol; trip 25 % LFL = 1.00 % vol; molar volume 24.05 L/mol at 20 °C
[A2] Reference room 30.0 m3, ceiling 12.0 m2, height 2500 mm
[B1] 100 W PEM stack at 1.9 V/cell: I x N = 52.6 A, 2.73 x 10^-4 mol/s, 0.39 L/min; design leak 5 L/min is 13 times this
[B2] Inventory limit (1 % of room volume): 300 L at 1 atm, 25.1 g
[B3] H2Bench 2 L tank at 300 kPa gauge: 7.9 L (2.6 % of the limit); 10 L cylinder at 200 bar: 1.75 m3, 5.8 times the limit
[B4] Restrictor for 5 L/min: orifice 0.13 mm at 10 bar gauge, 0.21 mm at 3 bar gauge (choked, Cd 0.8)
[C1] Ceiling layer 0.3 m x 12 m2 = 3.6 m3
[C2] 10 % LFL: layer needs 14 L, 2.9 min at 5 L/min; whole room 120 L, 24 min
[C2] 25 % LFL: layer needs 36 L, 7.2 min at 5 L/min; whole room 300 L, 60 min
[C2] 100 % LFL: layer needs 144 L, 28.8 min at 5 L/min; whole room 1200 L, 240 min
[D1] Steady well-mixed (and exhaust) concentration, 5 L/min: 0.200 % vol (5.0 % LFL) at 150 m3/h; 0.100 % vol (2.5 % LFL) at 300 m3/h; electrolyzer case 0.0157 % vol
[D2] 5.0 air changes per hour; time constant 12 min; 95 % of steady state after 36 min
[D3] High-level exhaust: at steady state all hydrogen leaves through the fan, so the upper layer settles at the exhaust value, 0.20 % vol (5.0 % LFL)
[D4] Plume flow equals 150 m3/h exhaust 2.28 m above the source; source to ceiling is 1.35 m, so the plume reaches the ceiling before it carries the exhaust flow and the upper layer extends down to about source height
[E1] Buoyancy flux 7.61 x 10^-4 m4/s3; plume rise to the sensor ports 1.175 m
[E2] Plume flow at the head 13.8 L/s; mean 0.60 % vol (15 % LFL); on the axis about 1.21 % vol (30 % LFL)
[E3] Plume velocity at the head 0.22 m/s; rise time 4.0 s
[E4] Head reading with the fan running: layer 5 % LFL plus plume 15 to 30 % LFL; plume mean above the warning, plume axis above the trip
[E5] Leak that brings the plume axis at the head to 25 % LFL: 3.8 L/min; plume mean to 10 % LFL: 2.7 L/min
[E6] Entrainment coefficient 0.08 to 0.12 instead of 0.10: head values x0.78 to x1.35, axis 24 to 41 % LFL
[E7] Plume top-hat radius at the sensor ports 141 mm (6/5 alpha z); port centre 0 mm from the apparatus centre on the drop rod (inside the plume), against 260 mm for the former wall position (outside)
[F1] Arrestor disc 25 x 2 mm, porosity 0.4, tortuosity 3.0: D_eff 9.2 x 10^-6 m2/s; slab 0.43 s; cavity 1.08 mL behind it, 90 % in 1.10 s; total 1.5 s
[F2] TRL 2 arrangement (5 mm disc, sensor 15 mm behind it): 21 s
[F3] Leak to valve closed: rise 4.0 + arrestor 1.5 + sensor t90 30 (assumed) + comparator 0.05 + relay 0.02 + valve 0.1 = 35.7 s
[F4] Trip to valve closed 0.17 s (R4 limit 2 s); alarm within 32 s of a step at the head (R4 limit 60 s)
[F5] Released before closing: 3.0 L at 5 L/min; plus downstream line (3 m of 4.3 mm bore at 10 bar gauge) 0.47 L
[F6] Fault to valve closed: watchdog 1.0 s + relay + valve = 1.12 s; sensor open or short via comparator 0.17 s; fan stop detected at 10 s then 0.12 s; airflow not proved by the pressure switch (fan stopped, duct blocked, shutter stuck) detected at 10 s then 0.12 s (R5 limit 2 s after detection)
[F7] Timed escalation, off-axis design leak (warning only): warning at 35.5 s, valve closed at 336 s (5.6 min); 28 L released at 5 L/min (9 % of the R9 inventory limit); 15 L at the 2.7 L/min warning threshold leak
[F8] Well-mixed room when the escalation closes the valve: 1.9 % LFL (steady state 5.0 % LFL); leaks below 2.7 L/min at the head give no warning and are not escalated
[G1] Duct velocity at 150 m3/h: 2.36 m/s; exhaust side K 3.44; make-up grille free area 0.024 m2, K 2.0
[G2] System pressure drop: 15.1 Pa at 150 m3/h; 60.5 Pa at 300 m3/h (room runs slightly below ambient)
[G3] TRL 2 spec (axial, 300 m3/h free air, 100 Pa shut-off, assumed): full speed 237 m3/h (7.9 air changes per hour), -21 % against the 300 m3/h boost
[G3] TRL 3 spec (mixed flow, 450 m3/h free air, 200 Pa shut-off, assumed): full speed 347 m3/h (11.6 air changes per hour), +16 % against the 300 m3/h boost
[G4] Continuous 150 m3/h at 43 % speed; fan power about 3.8 W continuous, 36 W on boost (35 W rated input assumed)
[G5] Room depression at boost 19.4 Pa across the make-up grille
[G6] Pressure switch, fan inlet tap against the room: 5.7 Pa at 150 m3/h, 30.5 Pa at full speed (347 m3/h); set point 2.8 Pa (half the continuous value) is reached at 106 m3/h; no flow gives about 0 Pa
[H1] Normal: 13.5 W
[H1] Warning (valve open, fan boost, sounder): 48.7 W
[H1] Trip (valve closed, fan boost, alarm): 40.3 W
[H2] Peak 48.7 W against the 60 W supply: margin x1.23; valve coil heat 8 W continuous; energy in normal state 0.32 kWh/day
[H3] With the oxygen sensor option: peak 49.2 W, margin x1.22
[J1] Bump test at 1.0 L/min: tube 3.11 m, 15.3 mL, delay 0.9 s; cup 114 mL, five volumes in 34 s; reading settles after about 67 s (R12 limit 120 s)
[J2] Span gas 1.36 L per test (with 15 s margin); a 34 L disposable cylinder gives about 25 tests
[J3] Log: one 16 B record per minute for 90 days = 2.07 MB, plus events; needs a board with 4 MB flash or more
[K1] Sounder 90 dB at 1 m: 90 dB at 1 m (free field)
[K1] Sounder 90 dB at 1 m: 80 dB at 3 m (free field)
[K1] Sounder 90 dB at 1 m: 76 dB at 5 m (free field)
[K2] Farthest point in the room 5.0 m: 76 dB, 16 dB above a 60 dB lab background
[L1] Sensor ports 175 mm below the ceiling (R1: 300 mm or less); fan grille top 80 mm below the ceiling
[L2] Controller top 1025 mm below the ceiling (R15: 1000 mm or more); beacon top 450 mm; supply on the floor
[M1] Installation estimate 415 min (6.9 h) with both wall openings; 300 min (5.0 h) with the openings made by others as builder's work, as R13 now scopes it (HGD-DDR-002; limit 240 min, +60 min)
[N1] BOM 21 lines, estimated cost of the constructable design $411.00; value-engineering target $265 (budget_usd, a hypothetical control target): $146.00 over the target (+55.1 %)
[N2] Without the fan and make-up grille ($63.00): $348.00
[N3] Options, priced but not in the total: line 20 $110.00; line 21 $450.00; with the oxygen sensor $521.00; with the alternative fan in place of line 9 $806.00

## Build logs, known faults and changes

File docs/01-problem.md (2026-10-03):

---
doc_id: HGD-PRB-001
title: H2Guard problem statement
project: H2Guard
doc_type: Problem statement
version: "0.8"
status: Draft
date: '2026-10-02'
author: Amish Chadha
license: CERN-OHL-S-2.0
revisions:
- version: "0.1"
  date: '2026-09-25'
  author: Amish Chadha
  change: Initial scaffold
- version: "0.2"
  date: '2026-09-25'
  author: Amish Chadha
  change: Populate to TRL 2 (problem, users, context, constraints, out of scope, prior work, open questions)
- version: "0.3"
  date: '2026-09-25'
  author: Amish Chadha
  change: TRL 3 update; open questions resolved by HGD-DDR-001 marked as adopted for TRL 3 pending Amish's review; cost figure from HGD-CAL-001
- version: "0.4"
  date: '2026-09-25'
  author: Amish Chadha
  change: Recommendations accepted by Amish (DDR-002); budget $265; resolved questions marked as decided
- version: "0.5"
  date: '2026-09-26'
  author: Amish Chadha
  change: Stronger sources
- version: "0.6"
  date: '2026-10-01'
  author: Amish Chadha
  change: Cost constraint restated against the value-engineering target after the design for construction (HGD-DDR-003)
- version: "0.7"
  date: '2026-10-02'
  author: Amish Chadha
  change: O2 and O3 decided by Amish on 2026-10-02 (HGD-DEC-001)
- version: "0.8"
  date: '2026-10-02'
  author: Amish Chadha
  change: Estimated cost updated to USD 411 after the decisions of 2026-10-02 were priced (HGD-CAL-001 v0.4)
---

# H2Guard problem statement

Small hydrogen setups in schools, university teaching labs, makerspaces and startups often have no gas detection or supply interlock, because commercial fixed detection systems are specified, priced and installed for industrial plants. H2Guard is an open, low-cost leak detector and ventilation interlock for one small room: it senses hydrogen at the ceiling, keeps the room ventilated, shuts the hydrogen supply when readings rise and fails safe when anything goes wrong. It is a research and teaching prototype, not a certified gas detection system.

## The problem

Hydrogen behaves differently from the gases most small labs are used to. It is flammable in air from about 4 % to 74 % by volume, and the energy needed to ignite it (about 0.02 mJ) is very low; it is also buoyant and diffuses quickly, so it escapes safely outdoors but collects under a ceiling in a poorly ventilated room ([US DOE hydrogen safety fact sheet](https://www1.eere.energy.gov/hydrogenandfuelcells/pdfs/h2_safety_fsheet.pdf)). It is invisible and odorless, so a person will not notice a leak.

Hydrogen use is spreading to smaller and less specialized users. Installed water electrolysis capacity reached about 2 GW in 2024 ([IEA, Global Hydrogen Review 2025](https://www.iea.org/reports/global-hydrogen-review-2025/executive-summary)), national programs are funding skills training (for example India's National Green Hydrogen Mission, [PIB, 2023](https://www.pib.gov.in/PressReleasePage.aspx?PRID=1888547)), and teaching benches such as the lab's own H2Bench put electrolyzers and fuel cells in ordinary classrooms.

Laboratory accidents show what happens when detection, grounding and supply control are missing. In March 2016 a hydrogen and oxygen gas mixture in an ungrounded 49 L tank exploded in a University of Hawaii lab; a postdoctoral researcher lost an arm, and the state regulator cited the university for 15 violations with $115,500 in fines ([C&EN, 2016](https://cen.acs.org/articles/94/web/2016/09/University-Hawaii-fined-115500-lab.html)), later settled at nine violations and $69,300 ([Honolulu Star-Advertiser, 2016](https://www.staradvertiser.com/2016/10/07/breaking-news/state-agrees-to-reduced-violations-fines-in-uh-lab-explosion/)). In May 2019 a hydrogen tank used by a fuel cell company at a technopark in Gangneung, South Korea, exploded, killing two people and injuring six ([Korea Herald, 2019](https://www.koreaherald.com/article/2006624)). An analysis of 576 statistically relevant events in the European hydrogen incident database found organizational and human factors in a large share of them ([Wen et al., 2022](https://www.sciencedirect.com/science/article/pii/S0360319922012976)), which argues for automatic safeguards that do not depend on a person noticing.

The gap for small users is threefold:

- **Cost and scale.** Fixed gas detection systems are sold as engineered packages for plants. A single certified hydrogen sensing element can cost about $249 on its own ([GasLab listing for the NevadaNano MPS sensor](https://gaslab.com/products/flammable-gas-sensor-nevada-nano-mps)), before the controller, valve, fan, alarm and installation.
- **Detection without action.** Where small labs do buy a detector, it is often a stand-alone alarm. Nothing closes the supply or increases ventilation, and nothing stops the gas flowing when the detector is unpowered or faulty.
- **No open reference.** There is no widely used open design that a teacher or a startup engineer can read, build, test and understand. Closed units hide their set points and failure behavior.

## Users and context

| User | Need | Context |
| --- | --- | --- |
| Secondary school or college science teacher | A detector and interlock for a hydrogen demonstration or H2Bench, which students can also learn from | Classroom or prep room, 20 to 60 m3, mains power, no gas engineer on site |
| University teaching lab technician | Protection for several student benches with small electrolyzers and fuel cells | Teaching lab with general ventilation, supervised sessions |
| Early-stage hydrogen startup | Interim protection for a small test room before a certified system is installed | Rented workshop or unit, small cylinders or electrolyzer output, limited budget |
| Makerspace or hackerspace | A clear rule set and hardware for members experimenting with electrolysis | Shared room, variable supervision |
| Analytical lab switching gas chromatography carrier gas to hydrogen | Room-level leak detection near a hydrogen generator | Existing lab, mechanical ventilation |
| Vocational trainer | A teaching unit for hydrogen safety: detection, set points, interlocks, bump tests | Training workshops for technicians |

## Operating environment

- Indoor room of about 20 to 60 m3 with a ceiling height of 2.4 to 3.5 m. The reference room for first-order numbers is 30 m3 (4 x 3 x 2.5 m).
- Hydrogen source: an electrolyzer of up to about 100 W, a metal hydride canister, or a small cylinder with a regulator and a flow restrictor. Pressure after the regulator 0 to 10 bar.
- Ambient 5 to 40 °C, 10 to 90 % relative humidity, non-condensing. Possible silicone, solvent or alcohol vapors from other lab work, which can poison or confuse some sensors.
- Mains power available (100 to 240 V, 50 or 60 Hz); outages possible.

## Constraints

- Garage-buildable prototype. Value-engineering target USD 265 (`project.yaml`, a hypothetical control target, not a limit), raised from USD 180 when Amish accepted the recommendation on 2026-09-25 (HGD-DDR-002). Estimated cost of the constructable design: USD 411, USD 146 over the target (HGD-CAL-001 v0.4).
- All self-built wiring is extra-low voltage (24 V DC). Mains is used only inside a certified power supply.
- Fail-safe by design: loss of power, a sensor fault or a controller fault must leave the hydrogen supply closed.
- Parts off the shelf where possible, with open firmware and published set points.
- Must not be presented as a certified gas detection system. It is a research and teaching prototype, and a real installation should use certified equipment.

## Out of scope

- Industrial or commercial installations, hydrogen refuelling stations, rooms classified as hazardous areas (ATEX or IECEx zones, NEC Class I divisions) and any use as the sole safeguard where a certified system is required.
- High-pressure storage indoors beyond the inventory limit proposed in the precis.
- Detection of other gases (oxygen depletion, carbon monoxide) except as a later option.
- Design of the gas system itself (regulator, tubing, flow restrictor), which belongs to the host project, for example H2Bench.

## Prior work

- **Standards.** ISO 26142:2010 covers performance of hydrogen detection apparatus for stationary applications ([ISO](https://www.iso.org/standard/52319.html)); it asks for a response time (t90) under 30 s, with alarms typically set at 25 % or 50 % of the lower flammability limit ([HySafe paper on sensor response time, 2017](https://hysafe.info/uploads/papers/2017/211.pdf)). NFPA 2, the Hydrogen Technologies Code, governs hydrogen installations in the United States ([NFPA](https://www.nfpa.org/product/nfpa-2-hydrogen-technologies-code/p0002code)). H2Guard uses these as design references only; it does not claim compliance.
- **Sensing elements.** Catalytic sensors burn the gas on a heated catalyst and read 0 to 100 % LFL; Figaro offers hydrogen-capable catalytic sensors such as the TGS6812 for stationary fuel cell leak detection ([Figaro, 2025](https://www.sensor-test.de/assets/Fairs/2025/ProductNews/PDFs/Figaro-Engineering-hydrogen-sensors-and-their-applications.pdf)). Metal oxide sensors such as the TGS2616 detect about 30 to 3,000 ppm hydrogen with reduced alcohol interference ([Figaro TGS2616-C00](https://www.figarosensor.com/product/docs/tgs2616-c00_product%20information(fusa)rev02.pdf)). Certified molecular property spectrometer sensors report 0 to 100 % LEL with t90 under 20 s and claim immunity to poisoning ([NevadaNano](https://nevadanano.com/mps-hydrogen-gas-sensor/)).
- **Incident learning.** The European HIAD 2.0 database and its analyses ([Wen et al., 2022](https://www.sciencedirect.com/science/article/pii/S0360319922012976)) and the University of Hawaii investigation ([UH report, 2016](http://www.hawaii.edu/news/wp-content/uploads/2016/07/Report-2-University-of-Hawaii.pdf)) supply the failure cases the concept is checked against.
- **Open designs.** A brief search found hobby hydrogen alarm projects built on single metal oxide sensors, but no documented open design that combines detection, ventilation and a fail-safe supply interlock. This has not been verified exhaustively.

## Open questions

Decided by Amish, 2026-09-25: go with recommendation (HGD-DDR-001 and HGD-DDR-002):

- First users: a university teaching lab first (D7).
- Sensor baseline: catalytic plus metal oxide pair, with the certified sensing element documented as the upgrade (D1).
- Inventory limit: 1 % of room volume at atmospheric pressure, or a flow restrictor, as a condition for H2Bench and other lab projects (D5).

Decided by Amish on 2026-10-02 (HGD-DEC-001):

- Oxygen depletion (O2): an oxygen sensor is added, as a standard kit option, whenever inert gas cylinders share the room.
- Set points and the inventory rule (O3): from the stricter of the national code and ISO 26142, and from the host institution's safety office where its rules are stricter; 10 % and 25 % LFL stay the defaults.

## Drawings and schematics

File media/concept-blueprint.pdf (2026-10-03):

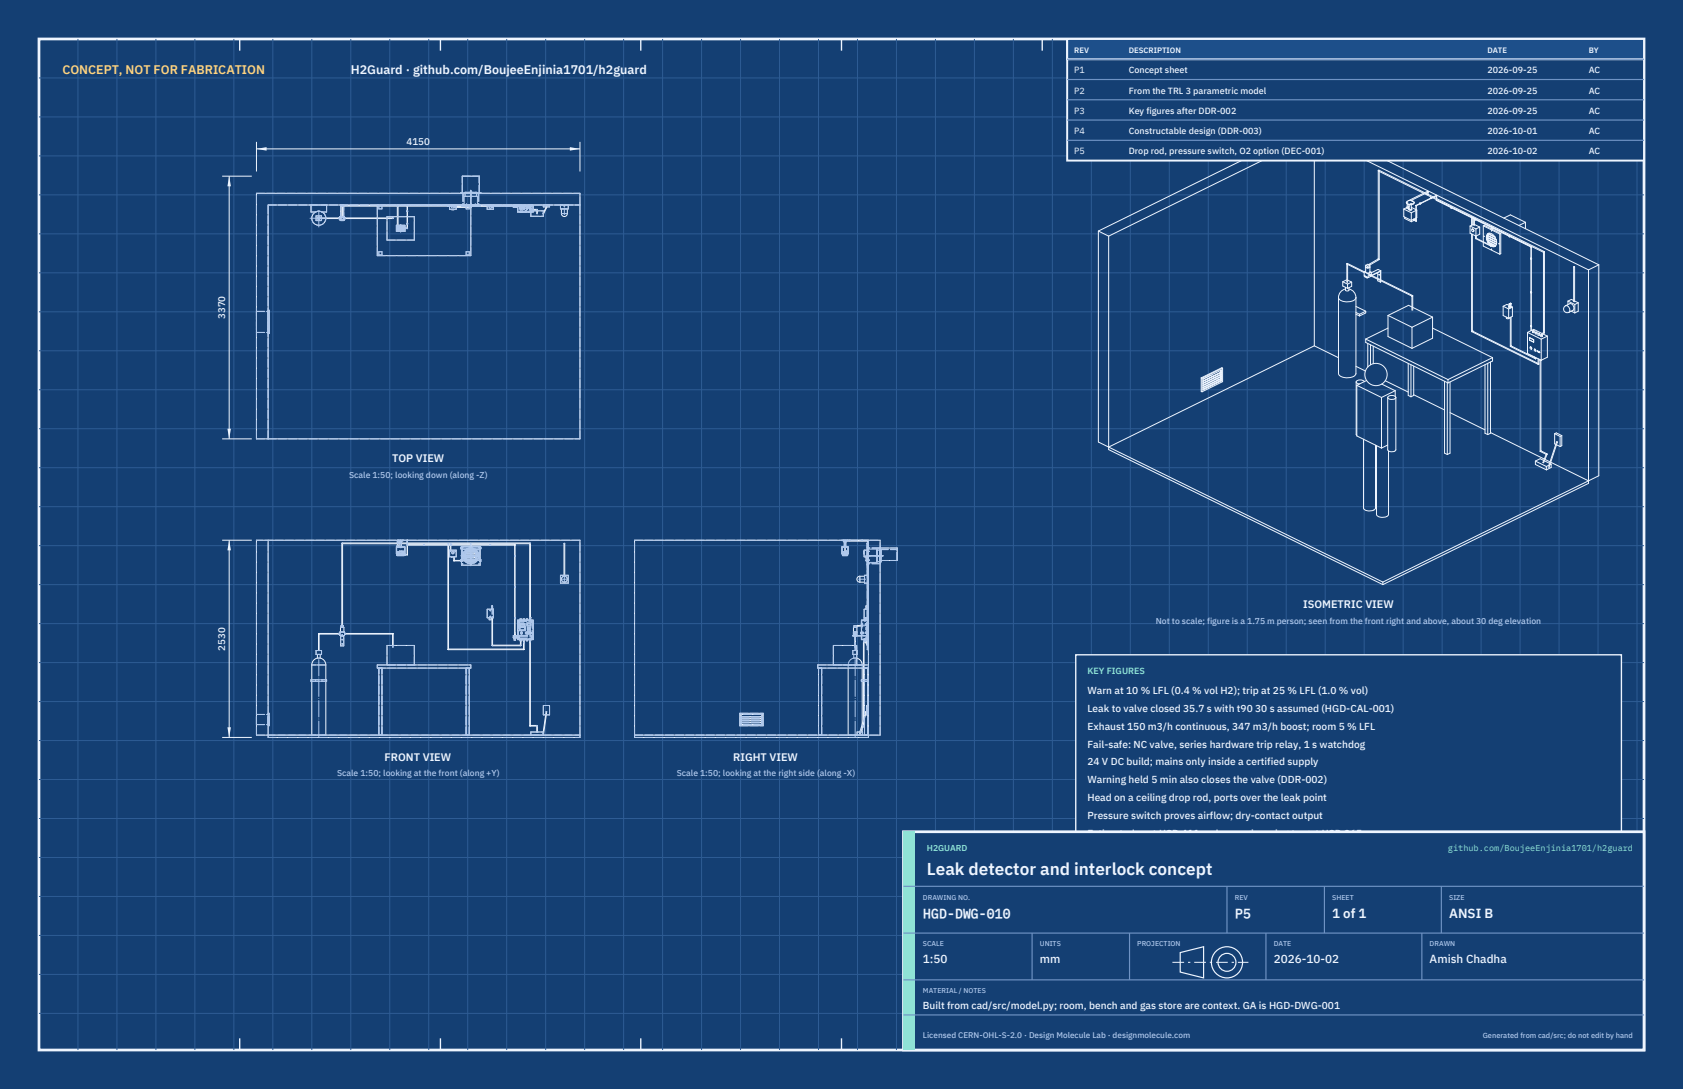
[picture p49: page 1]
CONCEPT, NOT FOR FABRICATION; H2Guard · github.com/BoujeeEnjinia1701/h2guard; FRONT VIEW; TOP VIEW; RIGHT VIEW; ISOMETRIC VIEW; REV; DESCRIPTION; DATE; Concept sheet; From the TRL 3 parametric model; Key figures after DDR-002; Constructable design (DDR-003); Drop rod, pressure switch, O2 option (DEC-001); H2GUARD; github.com/BoujeeEnjinia1701/h2guard; DRAWING NO. HGD-DWG-010; REV P5; SHEET 1 of 1; SIZE ANSI B; SCALE 1:50; UNITS mm; PROJECTION; DRAWN Amish Chadha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

Scale 1:50; looking down (along -Z)

Not to scale; figure is a 1.75 m person; seen from the front right and above, about 30 deg elevation

KEY FIGURES
Warn at 10 % LFL (0.4 % vol H2); trip at 25 % LFL (1.0 % vol)
Leak to valve closed 35.7 s with t90 30 s assumed (HGD-CAL-001)
Exhaust 150 m3/h continuous, 347 m3/h boost; room 5 % LFL
Fail-safe: NC valve, series hardware trip relay, 1 s watchdog
24 V DC build; mains only inside a certified supply
Warning held 5 min also closes the valve (DDR-002)
Head on a ceiling drop rod, ports over the leak point
Pressure switch proves airflow; dry-contact output
Estimated cost USD 411; value-engineering target USD 265

Scale 1:50; looking at the front (along +Y)

Scale 1:50; looking at the right side (along -X)

Leak detector and interlock concept

MATERIAL / NOTES
Built from cad/src/model.py; room, bench and gas store are context. GA is HGD-DWG-001

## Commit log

2026-09-25 Initial scaffold: standard open hardware layout, CERN-OHL-S v2 + MIT licenses
    Claude-Session: https://claude.ai/code/session_01XuhhSU4W6fYhgCfURbrkut
    [bom.csv]
2026-09-25 Populate to TRL 2: problem, requirements, precis, concept media, BOM and README use cases
    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
    [bom.csv]
2026-09-26 Advance to TRL 3: DDR-001, CAL-001 sizing, parametric model with STEP/STL, GA drawing, priced BOM; TRL 4 on hold
    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
    [bom.csv, controller.step, controller.stl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]
2026-09-26 Accept all recommendations (DDR-002), switch footer to designmolecule.com, add README write-up with new inspiration point
    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
    [controller.step, detector-head.step, exhaust-fan.step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]
2026-09-27 Product appearance model and photoreal renders
    Adds cad/src/product_model.py (appearance model for renders only, all main
    dimensions from model.py) and Blender renders in media/render-*.png,
    captioned with the project, repository and viewing direction. README leads
    with the product render; trl stays 3.
    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
2026-10-01 Image quality pass: legible exploded views, flow diagrams and drawing sheets
    Kit 1.6.1 image layout: the parts list sits in its own column, number bubbles sit on visible parts and never overlap, small parts get a leader, pictures are cropped to the subject, flow labels keep numbers with their units, and sheet captions and the revision table no longer overprint. Concept images, blueprint and general arrangement sheet regenerated; repo-specific labels moved clear of other text and lines.
2026-10-01 Kit 1.7.0: constructable design, illustrated build plan and design decisions register
    The design is now constructable: every part can be made and fits its neighbours, with each change recorded in a Design for construction decision record (made under Amish's 2026-09-30 instruction; ope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
    FlexHand also credits Dr. Geeti Chadha as a contribut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
    [bom.csv, controller.step, controller.stl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]
2026-10-02 Record Amish's approval of the open-decision recommendations
    Amish approved the recommendation on every open decision in the design decisions register ("i approve your recommendations for all 555 open decisions.", 2026-10-02). Each decision is moved to Decisio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
2026-10-03 Carry approved follow-ups into the design and redo photoreal renders
    Amish approved the follow-up actions from the open-decision sign-off ("APPROVED CHANGES, COMPLETE THESE", 2026-10-02), the design-for-construction change tables in ten repos, the last wave's open dec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
    [bom.csv, controller.step, controller.stl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]
2026-10-03 Record Amish's 2026-10-03 decisions; FlatTrike fork and PotPress guard fixes
    Amish, 2026-10-03: "PalletPilot - i accept it"; "FlatTrike - i accept your design recommendation, proceed and execute the solution for fork direction or caster"; "PotPress - move forward with the four guard fixes. I accept the cost."; "GravitySort - i accept your recommendation"; "TIght Margins - i accept the margins"; "Cost over target - i accept all the cost variations and overruns". FlatTrike knuckle forks turned to trail (35 mm trail); PotPress finer mesh, small-hole plates, top beam and crank bracket covers, ISO 13857 desk check now met on paper. Registers, requirements, drawings, pictures, renders and PDFs upd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

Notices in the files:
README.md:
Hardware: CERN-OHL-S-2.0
